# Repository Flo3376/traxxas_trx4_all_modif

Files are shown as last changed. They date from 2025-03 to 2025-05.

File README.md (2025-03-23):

# 🚗 Projet TRX4 Sport Hummer – Upgrade et Documentation complète

> 🇬🇧 [Switch to English version](./README.en.md)

Bienvenue sur ce projet de modification complète du **Traxxas TRX4 Sport 1/10**, basé à l'origine sur des éléments publiés sur Thingiverse, mais entièrement remis au propre, restructuré et enrichi.  
L’objectif est de proposer un **montage propre, solide, et documenté section par section**, avec une **carrosserie type Hummer** se montant en lieu et place, sans aucune modification des pièces d’origine.

---

## 🎯 Objectifs

- Offrir une **carrosserie réaliste** qui se monte comme si elle venait directement de chez Traxxas
- Ajouter une **gestion d’éclairage maison**, quelques options pratiques pour l’utilisation et le stockage
- Garder **la compatibilité maximale** avec les options d’origine (2 vitesses, différentiels débrayables…)
- Rester simple à monter, **sans découpe ni bidouillage** destructif (idéal pour ne pas casser la garantie)

---

## 🔧 Moyens et outils

Ce projet est réalisé entièrement **par un passionné** : modélisation, câblage, code et documentation.

- 🧩 **Conception 3D** : [Fusion 360](https://www.autodesk.com/products/fusion-360)
- 🔌 **Électronique** : schémas réalisés avec [Fritzing](https://fritzing.org/)
- 💡 **Firmware** : développé avec [Arduino IDE](https://www.arduino.cc/en/software)
- 🖨️ **Fabrication** :
  - Imprimante 3D avec buse de 0.8mm (robustesse)
  - Impression en **PETG**
  - Fer à souder de base, composants électroniques accessibles

Chaque section (carrosserie, électronique, firmware…) contient ses propres fichiers, schémas, images et instructions détaillées.

---

## 📂 Sommaire des sections

| Section | Description |
|---|---|
| [🛠️ Carrosserie](./carrosserie/README.md) | Montage de la coque Hummer, supports imprimés, ajustement sans modif. |
| [⚡ Électronique](./electronique/README.md) | Soudure, schéma de câblage, composants utilisés. |
| [💾 Firmware](./firmware/README.md) | Flash du microcontrôleur, gestion de l’éclairage, code Arduino. |

---

## 🧠 Pour qui ?

Ce projet est **ouvert à tous** : découpé en modules indépendants pour que chacun puisse piocher ce qui l’intéresse.  
Il est pensé pour être accessible à **des débutants débrouillards** comme à des passionnés expérimentés.  
L’ambition est de **tout expliquer simplement**, même si la doc évoluera au fil du temps.

🙏 Merci d’être indulgent : certaines approches sont simples, parfois pas optimales, mais pensées pour être faisables sans matériel pro.

---

## 🚀 Évolution & perspectives

- ✅ Une **télémétrie de base** est déjà intégrée
- 🛰️ Une **boîte noire GPS** est envisagée à terme
- 🧪 Ce projet est vivant : vos retours et suggestions sont les bienvenus

---

## 💬 Rejoindre la communauté

Pour discuter du projet, poser vos questions, ou partager vos montages :  
➡️ **[Rejoignez le serveur Discord](https://discord.gg/4V3BPrqjAZ)**

---

## ☕ Me soutenir ?

Ce projet m’a demandé **pas mal de temps, de prototypage, de documentation et de tests**.  
Je ne cherche pas à me payer une villa au Bahamas 😅 — mais si ce travail vous aide et que vous voulez me remercier...

🎁 **Un petit don pour m’aider à m’acheter 2 bobines de PETG, une boîte de visserie ou quelques inserts ferait super plaisir !**  
👉 [Faire un don via PayPal](https://www.paypal.com/donate/?hosted_button_id=264K3SDVHKDK2)

---

👉 **Explorez les différentes sections via le sommaire ci-dessus pour commencer l'aventure !**

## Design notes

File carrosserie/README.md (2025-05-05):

# 🛠️ Carrosserie – Montage et Fixation

## PRÉAMBULE

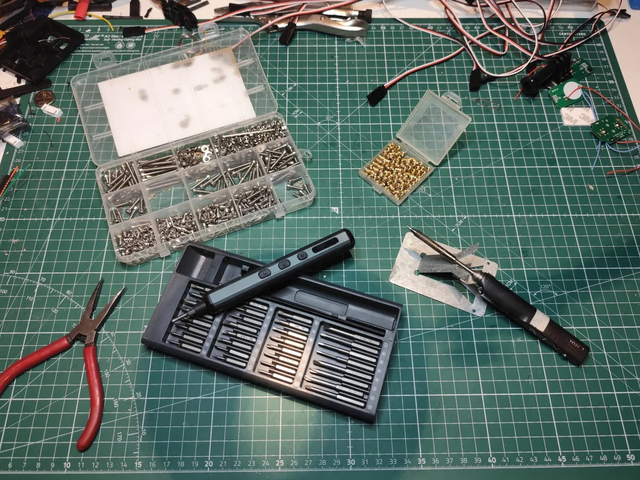
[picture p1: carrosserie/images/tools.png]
Outils


Faut être clair : ce projet va te prendre 100 heures facile. Impression, ponçage, ajustements, montage... Et tout ce temps, ton 4x4 restera à poil sur des cales, aussi mobile qu’un meuble IKEA pas monté.

C’est pas une bricole du dimanche, c’est un chantier. Si t’es pas prêt à y passer tes soirées, tes week-ends et à ruiner une chemise avec de la cyano, c’est maintenant qu’il faut faire demi-tour.

Matos minimum :
- Un kit de visserie 3 mm métrique (perso j’ai pris un mille-pièces, c’est pas pour frimer, c’est pour survivre).

- Des inserts filetés 3 mm, les vrais, ceux qui tiennent.

- D’un fer à souder de précision, pas ton vieux machin à griller les ESC.

- Et un joyeux bordel sur ton établi. Parce qu’un espace trop propre, c’est pas crédible. Et franchement, t’as déjà vu un maker qui bosse dans un bloc opératoire ?

- Du café. Beaucoup. En poudre, en grain, en perfusion si nécessaire. Sans ça, t’iras pas au bout. Si t’en arrives à infuser des copeaux de PLA pour rester éveillé, t’as été trop loin.

Et quand tu peindras ta caisse... libre à toi d’y mettre la couleur que tu veux. Tant que c’est couleur sable, bien sûr.

---

## Étape 1 – Les chandelles

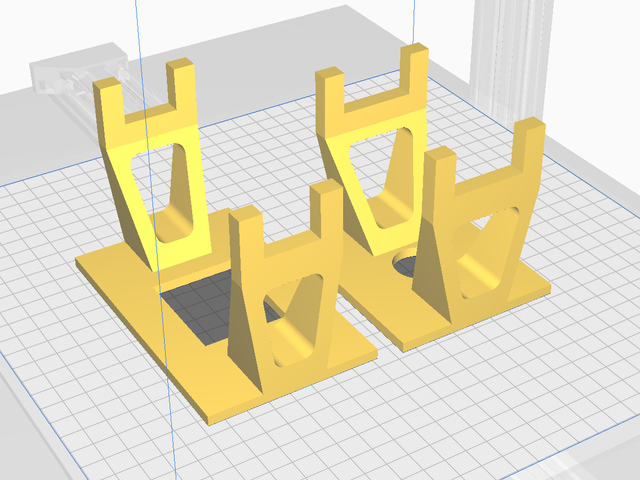
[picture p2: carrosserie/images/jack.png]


[📦 STL des chandelles avant](https://github.com/Flo3376/traxxas_trx4_all_modif/raw/main/carrosserie/parts/jack_stands/jack_stands_F.stl)
[📦 STL des chandelles arrière](https://github.com/Flo3376/traxxas_trx4_all_modif/raw/main/carrosserie/parts/jack_stands/jack_stands_R.stl)

On va commencer par imprimer les chandelles:
- 0.8mm pour la buse
- Orientation : socle vers le bas, évidemment. Pas la peine de faire les malins avec des supports tordus dès le départ. Ça dérapera bien assez tout seul plus tard.
- Adhérence par jupe conseillée
- support oui

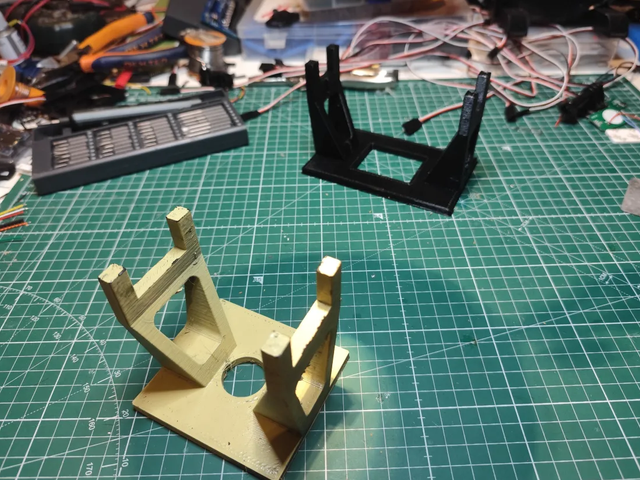
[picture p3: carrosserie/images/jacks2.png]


La chandelle avec le rond dans le socle c'est pour le train avain, celle avec le trou carré, tu devines pour quoi c’est....
Si tu bloques déjà ici... comment dire... Ça promet pour la suite. Vraiment.

## Étape 2 – Dépose des éléments en trop
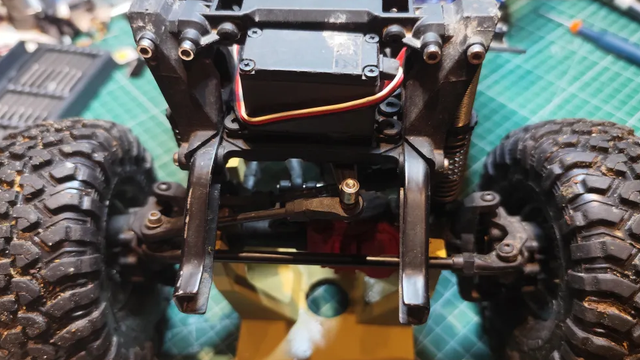
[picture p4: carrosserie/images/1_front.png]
Avant

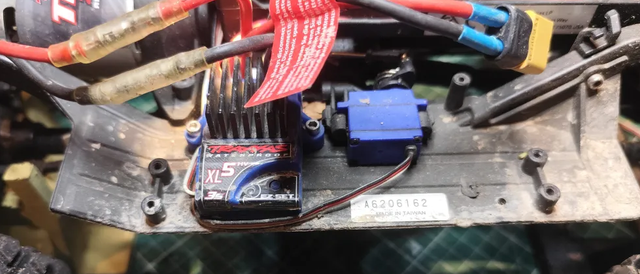
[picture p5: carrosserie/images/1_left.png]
Gauche

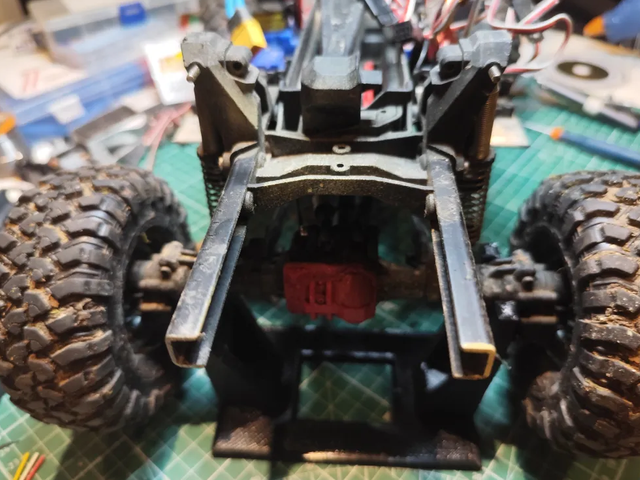
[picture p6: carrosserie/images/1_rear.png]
Arrière

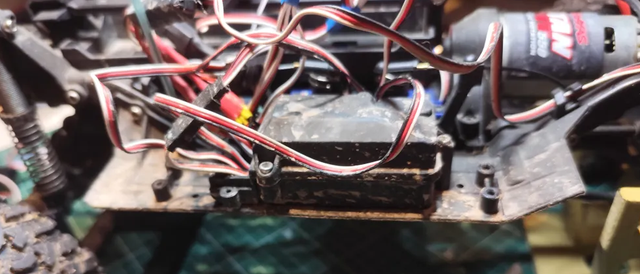
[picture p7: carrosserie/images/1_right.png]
Droites


Pas de quartier :

- Supports de carrosserie

- Supports de pare-choc

- Marchepieds

Tout ça, dehors. On vire tout ce qui dépasse. Ce qui reste doit être prêt à accueillir du neuf, du solide, du printé maison.

Les photos montrent une version équipée de la boîte 2 rapports et des commandes de blocage de ponts. Si t’as pas ça, pas grave. Mais sache que t’es déjà jaloux, un peu.

🛠️ Note sérieuse :
À ce stade, y’a aussi le support batterie qui pourrait bien y passer.
Je dis rien pour l’instant, mais j’ai une idée qui va peut-être émerger. Ou exploser. On verra. Mais ça sera une option 

💥 Concernant le câblage :
Ne paniquez pas si c’est un sac de nœuds. Si vous voyiez le câblage dans ma tête, vous relativiseriez tout de suite. Comme on dit chez nous :

> "Tous les étages sont câblés, mais pour le voltage, on repassera."

🔍 Remarque :
Il manque une pièce sur le train arrière, celle qui relie les suspensions. Elle n’est pas forcément à démonter, c’est juste que je l’ai perdue lors d’un road trip sans carrosserie. Si vous, vous l’avez encore, tant mieux. Sinon, bienvenue au club.

Et pendant qu’on y est : un petit nettoyage, ça mange pas de pain. C’est quand même plus agréable de bosser sur un engin propre.
(Et non, pas de blague douteuse sur "votre engin", merci. On a dit propre.)

## Étape 2 – La charnière de capot avant

[📦 STL de la charnière avant](https://github.com/Flo3376/traxxas_trx4_all_modif/raw/main/carrosserie/parts/hinge_hood_front_v3/hinge_hood_front_v3.stl)

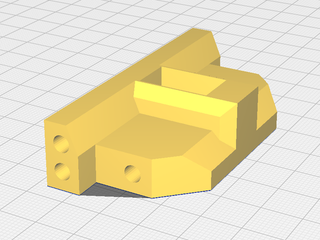
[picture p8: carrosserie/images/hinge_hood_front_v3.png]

- 0.8mm pour la buse
- À imprimer comme sur l’image.
Pourquoi ? Pour éviter que la pièce se fasse cisailler au premier face-à-face non consenti avec un obstacle. Ça semble con, mais tu seras content que ça tienne.
- support non

---

⚙️ Première pièce à installer.
Il vous fraudra :
- 6 inserts
- 4 vis en M3x10mm

---

⚠️ Précautions à prendre pour pas faire n’importe quoi dès le début :
- Afin de rentrer les inserts proprement et sans forcer comme un goret, il faut les chauffer quelques instants à température élevée.
Mon fer, lui, démarre à 300°C par défaut. C’est pas pour faire style, c’est parce que ça marche.

Et voici un dicton d’un grand sage – gravé par la douleure. À mémoriser absolument :
> Ta main tremblera, ton insert tombera.
 Le rattraper tu voudras.
 Ce réflexe à la con, tu auras.

- Serrage à la main, pas comme un bourrin avec une visseuse.
- Pas de rondelles : de toute façon ça passe pas.
- Pas de frein filet, inutile ici.
- Et la face plane vers l’avant, pas besoin de vous faire un dessin (enfin si, y’a les photos).

>la dépose des roues avant n'est pas obligatoire, mais ça peut être pratique

---
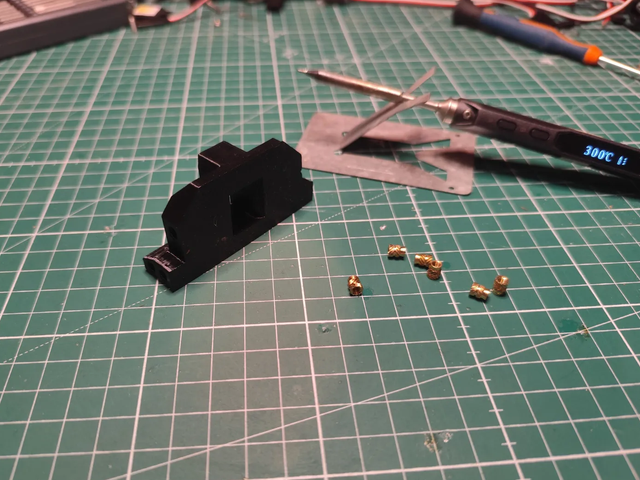
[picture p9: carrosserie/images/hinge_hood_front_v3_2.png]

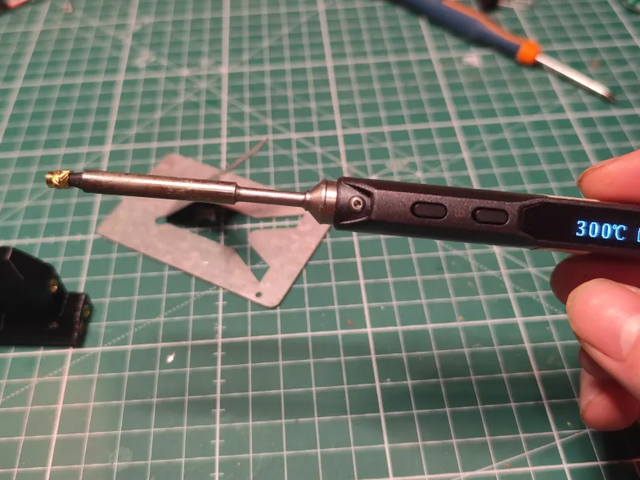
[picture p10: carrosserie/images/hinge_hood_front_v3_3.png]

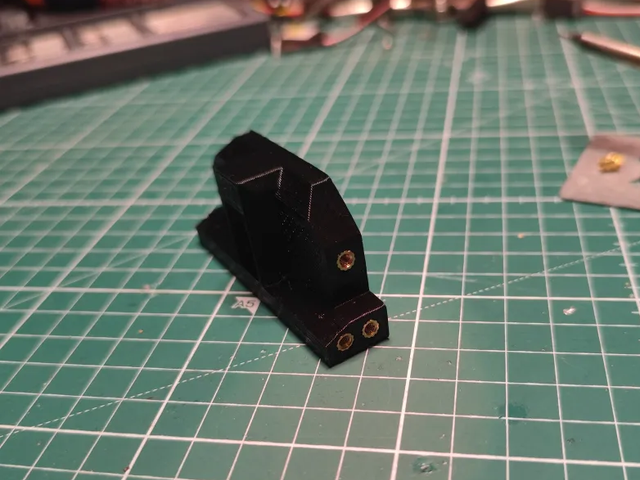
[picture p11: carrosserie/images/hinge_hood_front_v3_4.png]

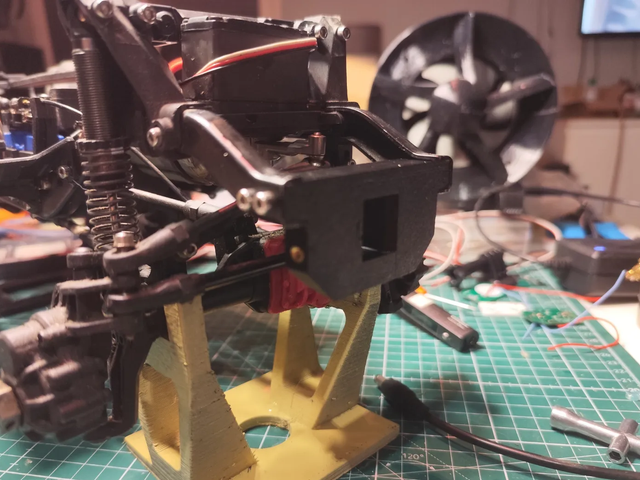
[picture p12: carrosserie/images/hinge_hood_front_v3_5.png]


## Étape 3, 4, 5 et, ...et... et pis merde– Le capot, son support, la façade,...

[📦 STL du support capot](https://github.com/Flo3376/traxxas_trx4_all_modif/raw/main/carrosserie/parts/hood_mount_frame_v3/hood_mount_frame_v3.stl)
[📦 STL de face avant](https://github.com/Flo3376/traxxas_trx4_all_modif/raw/main/carrosserie/parts/body_front_face_v2/body_front_face_v2.stl)
[📦 STL du capot](https://github.com/Flo3376/traxxas_trx4_all_modif/raw/main/carrosserie/parts/hood/hood.stl)
[📦 STL support des angels eyes](https://github.com/Flo3376/traxxas_trx4_all_modif/raw/main/carrosserie/parts/angel/angel_v1.stl)

---
support de capot

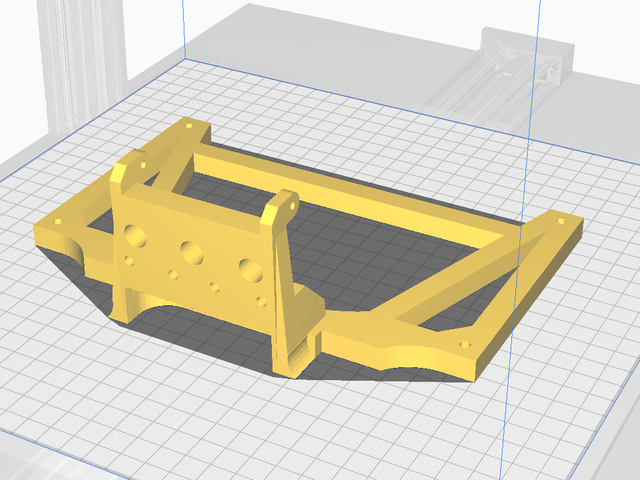
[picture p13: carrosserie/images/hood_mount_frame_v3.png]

- 0.8mm pour la buse
- Sens d'impression selon votre choix de défaut.
  - Comme sur l’image : ça va wrapper, mais comme c’est caché, ça restera notre petit secret.
  - Debout (façade contre plateau) : vous allez cramer du filament pour des supports, et si votre machine a la tremblote à en sucrer les fraises, c’est foutu.
  - Sur le côté : mélange des deux emmerdes. À vous de voir.
  - support non

---
façade avant

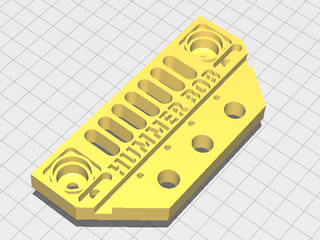
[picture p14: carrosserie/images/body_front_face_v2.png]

- 0.8mm pour la buse
- À imprimer comme sur l’image, si vous n'avez pas de soucis d'adhérence au plateau.
- support oui

---
angel eyes (optionnel)

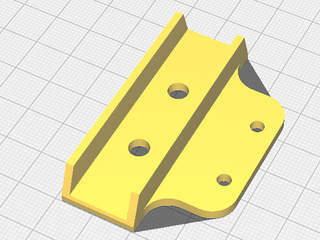
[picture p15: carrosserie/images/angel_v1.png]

- 0.8mm pour la buse
- À imprimer comme sur l’image.
- support non

---
capot

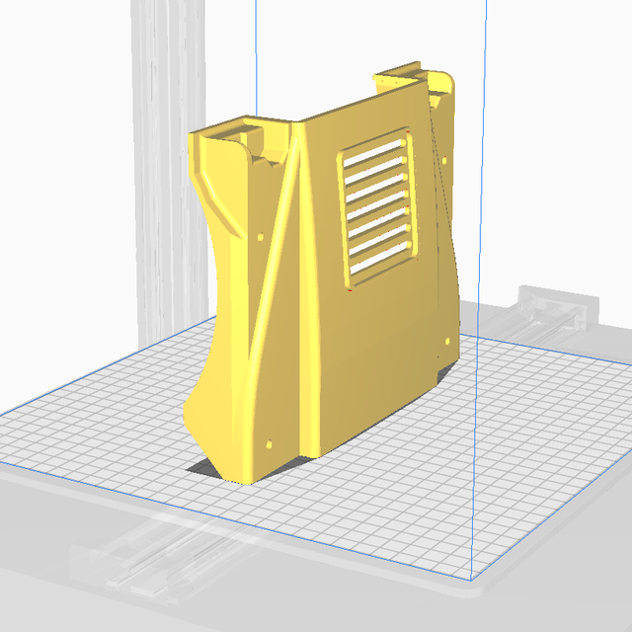
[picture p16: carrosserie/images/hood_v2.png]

- 0.8mm pour la buse
- À imprimer comme sur l’image pour éviter que les couches se voit trop
- imprimante au ralentie, ça limitera les dégats de colision.
- Adhérence par jupe obligatoire / radeau conseillé pour les machines un peu plus capricieuse
- support oui

---
Bon la ça va commencer à donner le sourrire.
Une fois que vous avez nettoyer les pièces, il va vous falloir:
- 8 insert (ça commence à faire mais vous avez 10 doigts, vous vous en sortirer)
- 4 ou 2 vis M3 x 10mm pour fixer la façade (je ne vous ai pas dit de la monter bordel.) Si vous ne montez pas l'option Angel eye c'est 4, sinon remplacer les 2 vis du centre par des M3x20mm.
- 2 vis M3 x 15mm  et 2 M3 x 18mm+ rondelle pour fixer le capot (range cette putain de visseuse, je ne le dirai pas 2 fois)
- 2 vis M3 x 12mm + si vous avez une lichette de frein filet léger

🛠️ Étapes de montage
- Pose des 8 inserts sur le support capot :
  - 4 sur la façade
  - 1 sur chaque coin du support
  >4 + 4 = 8, on valide.

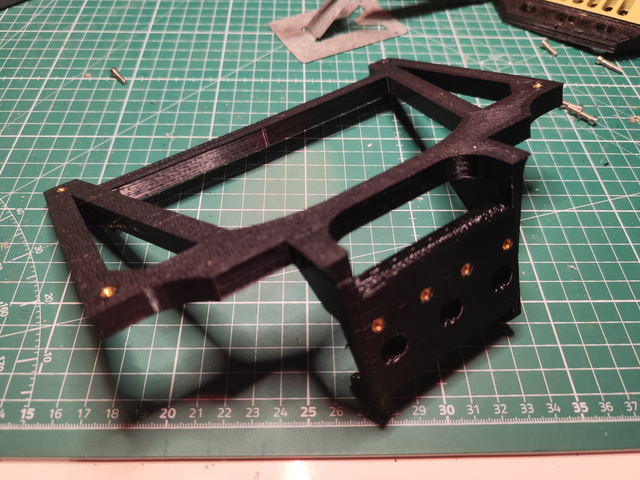
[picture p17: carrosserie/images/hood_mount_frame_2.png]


---

- Fixation de la façade :
  - Si vous utilisez les Angel Eyes :
    - Vissez les 2 vis externes
    - Glissez le support LED avec les deux LEDs déjà montées par le haut
      (si tu fais pas ça dans l’ordre, viens pas pleurer)
    - Puis serrez les 2 vis centrales
  - Sinon, 4 vis M3 x 10mm direct.

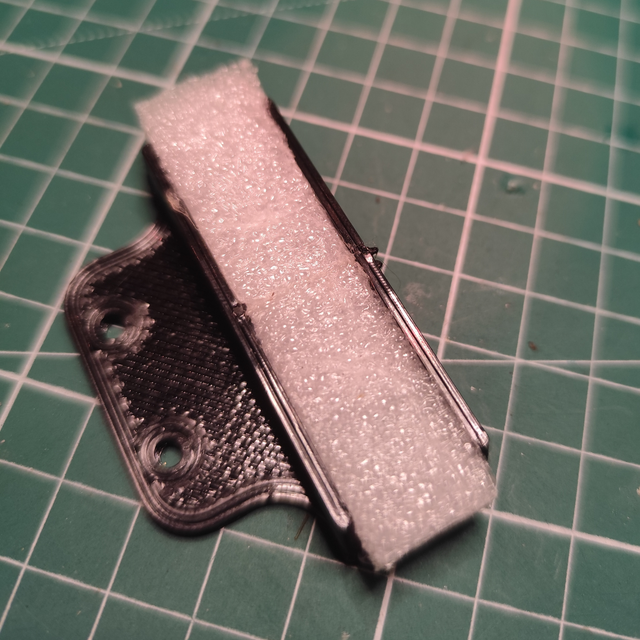
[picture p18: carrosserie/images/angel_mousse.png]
angel eye

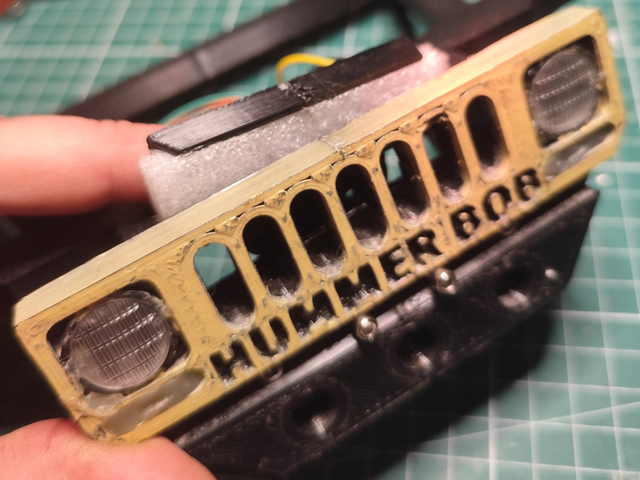
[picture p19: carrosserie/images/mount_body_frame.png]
façade

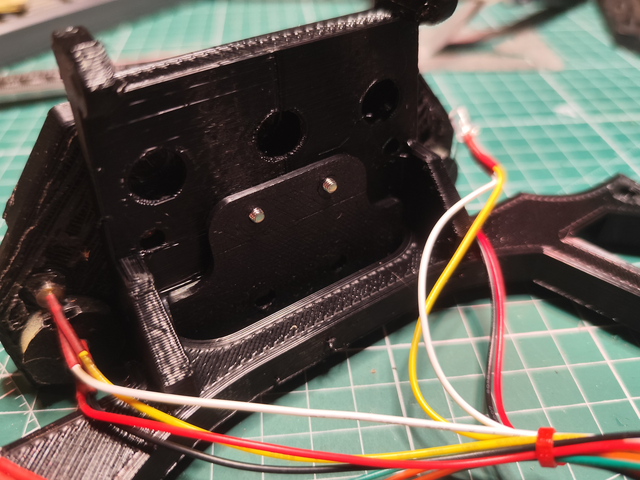
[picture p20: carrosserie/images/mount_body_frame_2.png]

---

- Fixation du support capot sur la charnière :
  - Utilisez les 2 vis M3 x 12 mm
  - Pour le premier montage ne mettez de frein filet
    > vous devrez certaine le déposer pour faciliter la suite du montage) ,
  - Pour le montage définitif, mettez une micro goutte de frein filet 
    > (Pas un bain. Une goutte. Sérieux.)
  - Serrez, puis desserrez d’un tour.
    > Vous ne le faites pas ? Vous allez la voir passer, la douille, surtout avec le frein filet.

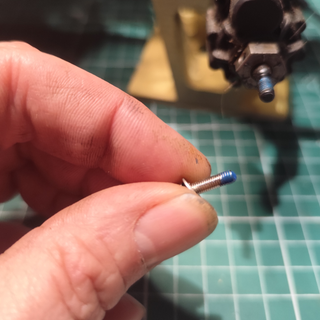
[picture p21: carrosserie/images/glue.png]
glue


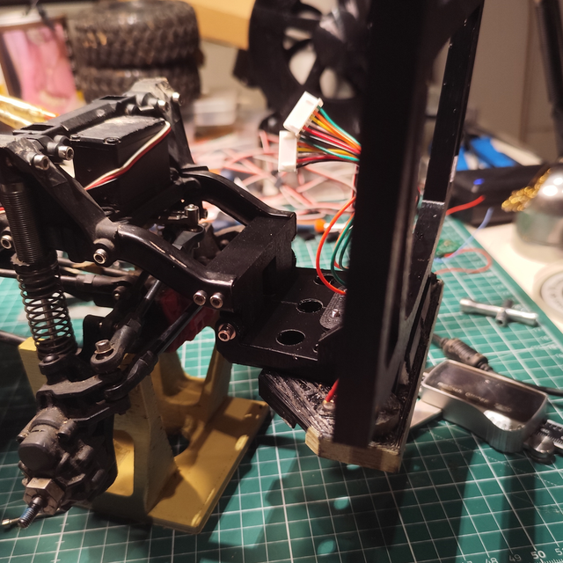
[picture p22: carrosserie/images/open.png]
open

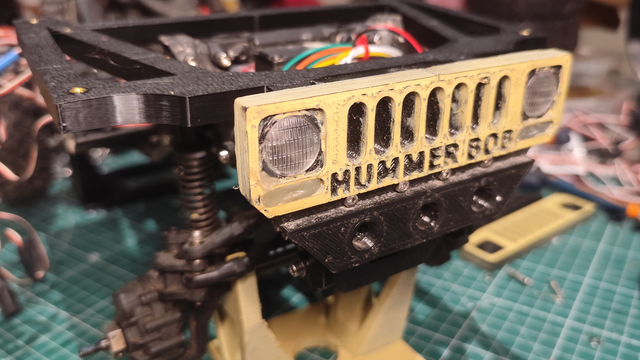
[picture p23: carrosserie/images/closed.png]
closed


---

- Pose du capot :
  - Allez-y, posez le capot, mais ne serrez rien pour l’instant.
  - Mettez les 2 vis de 18 mm sur les zones les plus épaisses, les 2 plus courtes (15 mm) à l’avant, côté museau.
  - Il y aura des ajustements, donc on garde de la marge.
  - Astuce : ne pas serrer tout de suite facilite l’engagement dans les inserts sans les ruiner. Et ça évite de tout recommencer.

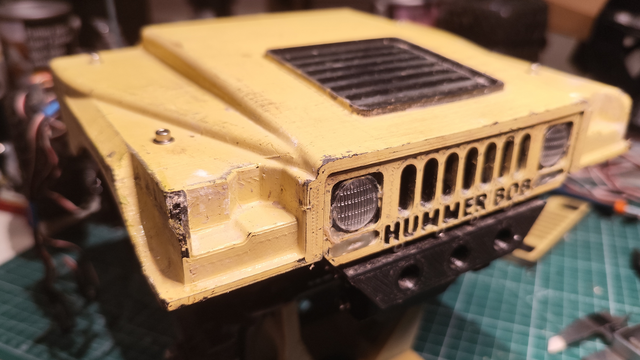
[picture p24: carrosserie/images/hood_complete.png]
hood_complete


Et voilà. On marque une pause, on recule de deux pas, et on admire.
Prenez 5 minutes pour souffler... et pour siroter un café.
Vous l’avez mérité.

## Étape 7 (enfin je crois), Préparation du rigidifieur arrière et des supports:

[📦 STL du rigidifieurt](https://github.com/Flo3376/traxxas_trx4_all_modif/raw/main/carrosserie/parts/rear_chassis_brace/rear_chassis_brace.stl)

rigidifieur arrière
- 0.8mm pour la buse
- À imprimer comme sur l’image, aucun piéges.

🧱 Le rigidifieur (aka la traverse qui tient la baraque)
Avant tout, faut préparer le rigidifieur, cette pièce qu’on vient se caler entre les deux longerons du châssis.

Il faut y poser 7 inserts. Pas 6. Pas 8. Sept.

Et prévoir 6 vis M3 x 10 mm avec rondelles pour la suite.

Si t’en rates un, tu vas t’en souvenir au moment de l’assemblage. Et ce sera trop tard. Donc on le fait bien maintenant, pendant que t’as encore les doigts intacts.

rigidifieur arrière

---
🔧 Le support droit/gauche (arrière)
[📦 STL du support droit et gauche](https://github.com/Flo3376/traxxas_trx4_all_modif/raw/main/carrosserie/parts/rear_mount_v2/rear_mount_right_v2.stl)

>Le support gauche → n’existe pas en STL, parce qu’on n’est pas là pour faire du copier-coller à la main.
>Il suffit de dupliquer le support droit dans Cura et d’activer la symétrie miroir sur l’axe X.

support arrière
- 0.8mm pour la buse
- À debout et pensez à dupliquer la piéces avec un symétrie en X.
- Supports conseillé

Les supports sont des pièces relativement massive qui vont supporter la carroserie et encaisser une partie des chocs
Pour chaque support il va falloir 3 ou 5 inserts (5 si vous pensez accrochez quelque chose au rigidifieur comme un atttelage, oups j'ai en trop dit sur une prochaine idée).
La pose des insert utilise une approche différente car dedans nous laisseront des vis permanantes.
La pose des inserts se fait par le dessous. et une fois poser, il faudra mettre des vis M3 x 18mm avec des rondelles aussi par le dessous.

La fixation/laison entre le rigidifieur et les supports se fait grace à des vis M3 x 12mm avec aussi des rondelles.

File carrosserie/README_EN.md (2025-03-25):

# 🛠️ Carrosserie – Montage et Fixation

## FOREWORD

Tools

Before diving into the wonderful world of custom-printed car bodies, let’s be clear: between printing time, painting (you're on your own here, Picasso), assembly, and all the fiddly adjustments that would make a Swiss watchmaker cry, expect to spend around 100 hours. Yep. One hundred. During that time, your beautiful 4x4 will be completely out of service—naked and sad, with nothing on its chassis.

You’ll need:
- A 3 mm metric screw kit (I got a 1000-piece one, because why not go overkill?).

- Threaded inserts for 3 mm screws.

- A small soldering iron to install those inserts properly (not your wire-soldering one, a real precision iron).

- And above all: a lot of clutter around your workspace. If it’s too clean, it doesn’t feel like a real maker zone. Chaos is fuel.

---

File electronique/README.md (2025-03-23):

# ⚡ Électronique – Schéma et Soudure

## Composants

- ESC
- Moteur brushless
- Batterie LiPo
- Récepteur

## Schéma de câblage

Schéma de câblage

| 🇬🇧 English | 🇫🇷 Français |
|---|---|
| Double-check all connections before powering up. | Vérifiez toutes les connexions avant d’alimenter le circuit. |

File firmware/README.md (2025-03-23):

# 💾 Firmware – Configuration et Code

## Préparation

- Installez PlatformIO ou Arduino IDE
- Branchez le microcontrôleur via USB

## Flash

```bash
pio run --target upload
```

## Code source

Le dossier `code/` contient les fichiers du firmware.

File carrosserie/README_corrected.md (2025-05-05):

# 🛠️ Carrosserie – Montage et Fixation

## PRÉAMBULE

Outils

Faut être clair : ce projet va te prendre 100 heures facile. Impression, ponçage, ajustements, montage... Et tout ce temps, ton 4x4 restera à poil sur des cales, aussi mobile qu’un meuble IKEA pas monté.

C’est pas une bricole du dimanche, c’est un chantier. Si t’es pas prêt à y passer tes soirées, tes week-ends et à ruiner une chemise avec de la cyano, c’est maintenant qu’il faut faire demi-tour.

Matos minimum :
- Un kit de visserie 3 mm métrique (perso j’ai pris un mille-pièces, c’est pas pour frimer, c’est pour survivre).

- Des inserts filetés 3 mm, les vrais, ceux qui tiennent.

- D’un fer à souder de précision, pas ton vieux machin à griller les ESC.

- Et un joyeux bordel sur ton établi. Parce qu’un espace trop propre, c’est pas crédible. Et franchement, t’as déjà vu un maker qui bosse dans un bloc opératoire ?

- Du café. Beaucoup. En poudre, en grain, en perfusion si nécessaire. Sans ça, t’iras pas au bout. Si t’en arrives à infuser des copeaux de PLA pour rester éveillé, t’as été trop loin.

Et quand tu peindras ta caisse... libre à toi d’y mettre la couleur que tu veux. Tant que c’est couleur sable, bien sûr.

---

## Étape 1 – Les chandelles

Chandelles

[📦 STL des chandelles avant](https://github.com/Flo3376/traxxas_trx4_all_modif/raw/main/carrosserie/parts/jack_stands/jack_stands_F.stl)
[📦 STL des chandelles arrière](https://github.com/Flo3376/traxxas_trx4_all_modif/raw/main/carrosserie/parts/jack_stands/jack_stands_R.stl)

On va commencer par imprimer les chandelles:
- 0.8mm pour la buse
- Orientation : socle vers le bas, évidemment. Pas la peine de faire les malins avec des supports tordus dès le départ. Ça dérapera bien assez tout seul plus tard.
- Adhérence par jupe conseillée
- - Support : **oui**

Chandelles

La chandelle avec le rond dans le socle c'est pour le train avant, celle avec le trou carré, tu devines pour quoi c’est....
Si tu bloques déjà ici... comment dire... Ça promet pour la suite. Vraiment.

## Étape 2 – Dépose des éléments en trop
Avant
Gauche
Arrière
Droites

Pas de quartier :

- Supports de carrosserie
- Supports de pare-choc
- Marchepieds

Tout ça, dehors. On vire tout ce qui dépasse. Ce qui reste doit être prêt à accueillir du neuf, du solide, du printé maison.

Les photos montrent une version équipée de la boîte 2 rapports et des commandes de blocage de ponts. Si t’as pas ça, pas grave. Mais sache que t’es déjà jaloux, un peu.

🛠️ Note sérieuse :
À ce stade, y’a aussi le support batterie qui pourrait bien y passer.
Je dis rien pour l’instant, mais j’ai une idée qui va peut-être émerger. Ou exploser. On verra. Mais ça sera une option 

💥 Concernant le câblage :
Ne paniquez pas si c’est un sac de nœuds. Si vous voyiez le câblage dans ma tête, vous relativiseriez tout de suite. Comme on dit chez nous :

> "Tous les étages sont câblés, mais pour le voltage, on repassera."

🔍 Remarque :
Il manque une pièce sur le train arrière, celle qui relie les suspensions. Elle n’est pas forcément à démonter, c’est juste que je l’ai perdue lors d’un road trip sans carrosserie. Si vous, vous l’avez encore, tant mieux. Sinon, bienvenue au club.

Et pendant qu’on y est : un petit nettoyage, ça mange pas de pain. C’est quand même plus agréable de bosser sur un engin propre.
(Et non, pas de blague douteuse sur "votre engin", merci. On a dit propre.)

## Étape 2 – La charnière de capot avant

[📦 STL de la charnière avant](https://github.com/Flo3376/traxxas_trx4_all_modif/raw/main/carrosserie/parts/hinge_hood_front_v3/hinge_hood_front_v3.stl)

charnière
- 0.8mm pour la buse
- À imprimer comme sur l’image.
Pourquoi ? Pour éviter que la pièce se fasse cisailler au premier face-à-face non consenti avec un obstacle. Ça semble con, mais tu seras content que ça tienne.
- Support : **non**

---

⚙️ Première pièce à installer.
Il vous faudra :
- 6 inserts
- 4 vis en M3x10mm

---

⚠️ Précautions à prendre pour pas faire n’importe quoi dès le début :
- Afin de rentrer les inserts proprement et sans forcer comme un goret, il faut les chauffer quelques instants à température élevée.
Mon fer, lui, démarre à 300°C par défaut. C’est pas pour faire style, c’est parce que ça marche.

Et voici un dicton d’un grand sage – gravé par la douleure. À mémoriser absolument :
> Ta main tremblera, ton insert tombera.
 Le rattraper tu voudras.
 Ce réflexe à la con, tu auras.

- Serrage à la main, pas comme un bourrin avec une visseuse.
- Pas de rondelles : de toute façon ça passe pas.
- Pas de frein filet, inutile ici.
- Et la face plane vers l’avant, pas besoin de vous faire un dessin (enfin si, y’a les photos).

>la dépose des roues avant n'est pas obligatoire, mais ça peut être pratique

---
charnière
charnière
charnière
charnière

## Étape 3, 4, 5 et, ...et... et pis merde– Le capot, son support, la façade,...

[📦 STL du support capot](https://github.com/Flo3376/traxxas_trx4_all_modif/raw/main/carrosserie/parts/hood_mount_frame_v3/hood_mount_frame_v3.stl)
[📦 STL de face avant](https://github.com/Flo3376/traxxas_trx4_all_modif/raw/main/carrosserie/parts/body_front_face_v2/body_front_face_v2.stl)
[📦 STL du capot](https://github.com/Flo3376/traxxas_trx4_all_modif/raw/main/carrosserie/parts/hood/hood.stl)
[📦 STL support des angels eyes](https://github.com/Flo3376/traxxas_trx4_all_modif/raw/main/carrosserie/parts/angel/angel_v1.stl)

---
support de capot

support
- 0.8mm pour la buse
- Sens d'impression selon votre choix de défaut.
  - Comme sur l’image : ça va wrapper, mais comme c’est caché, ça restera notre petit secret.
  - Debout (façade contre plateau) : vous allez cramer du filament pour des supports, et si votre machine a la tremblote à en sucrer les fraises, c’est foutu.
  - Sur le côté : mélange des deux emmerdes. À vous de voir.
  - Support : **non**

---
façade avant

support
- 0.8mm pour la buse
- À imprimer comme sur l’image, si vous n'avez pas de soucis d'adhérence au plateau.
- Support : **oui**

---
angel eyes (optionnel)

support
- 0.8mm pour la buse
- À imprimer comme sur l’image.
- Support : **non**

---
capot

support
- 0.8mm pour la buse
- À imprimer comme sur l’image pour éviter que les couches se voit trop
- imprimante au ralentie, ça limitera les dégats de collision.
- Adhérence : jupe obligatoire, radeau conseillé pour les machines un peu plus capricieuse
- Support : **oui**

---
Bon la ça va commencer à donner le sourrire.
Une fois que vous avez nettoyer les pièces, il va vous falloir:
- 8 insert (ça commence à faire mais vous avez 10 doigts, vous vous en sortirez)
- 4 ou 2 vis M3 x 10mm pour fixer la façade (je ne vous ai pas dit de la monter bordel.) Si vous ne montez pas l'option Angel eye c'est 4, sinon remplacez les 2 vis du centre par des M3x20mm.
- 2 vis M3 x 15mm  et 2 M3 x 18mm+ rondelle pour fixer le capot (range cette putain de visseuse, je ne le dirai pas 2 fois)
- 2 vis M3 x 12mm + si vous avez une micro-goutte de frein filet léger

🛠️ Étapes de montage
- Pose des 8 inserts sur le support capot :
  - 4 sur la façade
  - 1 sur chaque coin du support
  >4 + 4 = 8, on valide.

support

---

- Fixation de la façade :
  - Si vous utilisez les Angel Eyes :
    - Vissez les 2 vis externes
    - Glissez le support LED avec les deux LEDs déjà montées par le haut
      (si tu fais pas ça dans l’ordre, viens pas pleurer)
    - Puis serrez les 2 vis centrales
  - Sinon, 4 vis M3 x 10mm direct.

angel eye
façade
angel eye
---

- Fixation du support capot sur la charnière :
  - Utilisez les 2 vis M3 x 12 mm
  - Pour le premier montage ne mettez de frein filet
    > vous devrez certaine le déposer pour faciliter la suite du montage) ,
  - Pour le montage définitif, mettez une micro goutte de frein filet 
    > (Pas un bain. Une goutte. Sérieux.)
  - Serrez, puis desserrez d’un tour.
    > Vous ne le faites pas ? Vous allez la voir passer, la douille, surtout avec le frein filet.

glue

open
closed

---

- Pose du capot :
  - Allez-y, posez le capot, mais ne serrez rien pour l’instant.
  - Mettez les 2 vis de 18 mm sur les zones les plus épaisses, les 2 plus courtes (15 mm) à l’avant, côté museau.
  - Il y aura des ajustements, donc on garde de la marge.
  - Astuce : ne pas serrer tout de suite facilite l’engagement dans les inserts sans les ruiner. Et ça évite de tout recommencer.

hood_complete

Et voilà. On marque une pause, on recule de deux pas, et on admire.
Prenez 5 minutes pour souffler... et pour siroter un café.
Vous l’avez mérité.

## Étapes 7, 8 et 9 (enfin je crois), Préparation du rigidifieur arrière et des supports:

[📦 STL du rigidifieur](https://github.com/Flo3376/traxxas_trx4_all_modif/raw/main/carrosserie/parts/rear_chassis_brace/rear_chassis_brace.stl)

rigidifieur arrière
- 0.8mm pour la buse
- À imprimer comme sur l’image, aucun pièges.

🧱 Le rigidifieur (aka la traverse qui tient la baraque)
Avant tout, faut préparer le rigidifieur, cette pièce qu’on vient se caler entre les deux longerons du châssis.

Il faut y poser 7 inserts. Pas 6. Pas 8. Sept.

Et prévoir 6 vis M3 x 10 mm avec rondelles pour la suite.

Si t’en rates un, tu vas t’en souvenir au moment de l’assemblage. Et ce sera trop tard. Donc on le fait bien maintenant, pendant que t’as encore les doigts intacts.

rigidifieur arrière

---
🔧 Le support droit/gauche (arrière)
[📦 STL du support droit (et gauche par symétrie)](https://github.com/Flo3376/traxxas_trx4_all_modif/raw/main/carrosserie/parts/rear_mount_v2/rear_mount_right_v2.stl)

>Le support gauche → n’existe pas en STL, parce qu’on n’est pas là pour faire du copier-coller à la main.
>Il suffit de dupliquer le support droit dans Cura et d’activer la symétrie miroir sur l’axe X.

support arrière
- 0.8mm pour la buse
- À debout et pensez à dupliquer la pièces avec un symétrie en X.
- Supports conseillés

Les supports sont des pièces relativement massives, qui vont supporter la carrosserie et encaisser une partie des chocs.

Pour chaque support, il va falloir :
- 3 inserts en usage classique
- 5 inserts si vous comptez fixer quelque chose au rigidifieur (genre un attelage, oups... j’en ai trop dit sur une idée future)

La pose des inserts ici est un peu différente : on laisse les vis dedans, volontairement.
Les inserts se posent par le dessous, et une fois en place, on met des vis M3 x 18 mm avec rondelles, également par dessous.

support arrière
support arrière2
support arrière3
support arrière4

La fixation/laison entre le rigidifieur et les supports se fait grace à des vis M3 x 12mm avec aussi des rondelles.

support arrière5
support arrière6

Et voilà.
À force de parler de rondelles, j’ai envie de saucisson.

Allez, apéro. 🍷🧀

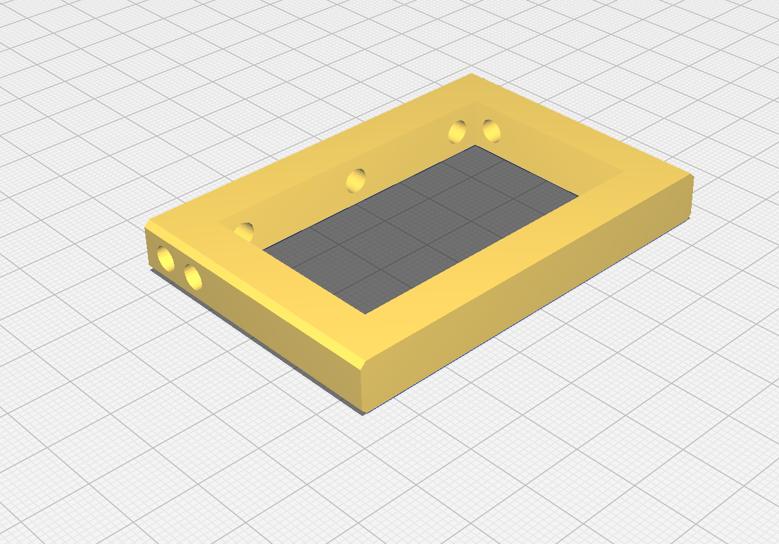
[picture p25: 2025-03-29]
carrosserie/parts/rear_chassis_brace/rear_chassis_brace.png

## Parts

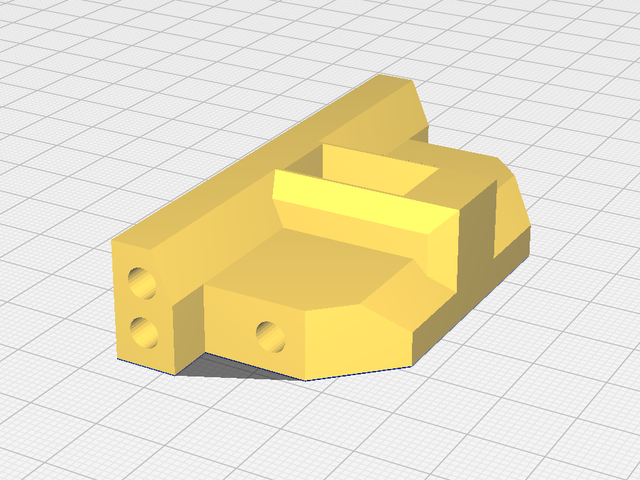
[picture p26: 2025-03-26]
carrosserie/parts/hinge_hood_front_v3/hinge_hood_front_v3.png

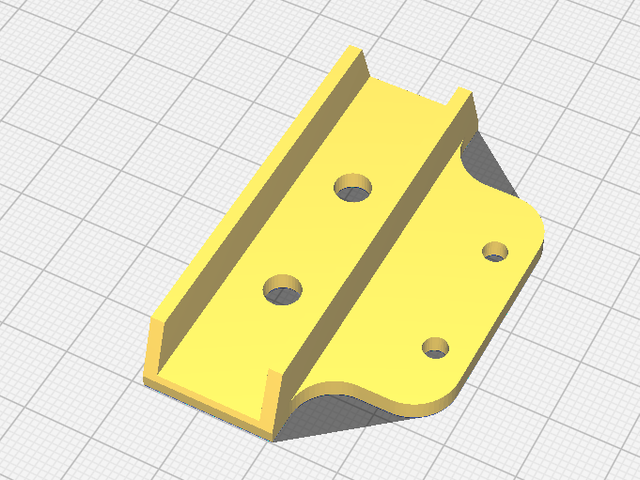
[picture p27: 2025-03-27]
carrosserie/parts/angel/angel v1.png

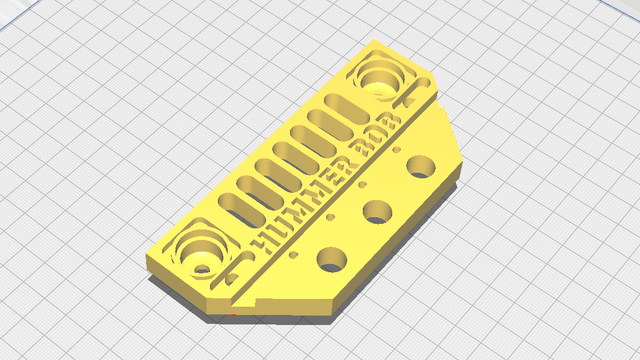
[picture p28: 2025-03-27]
carrosserie/parts/body_front_face_v2/body_front_face_v2.png

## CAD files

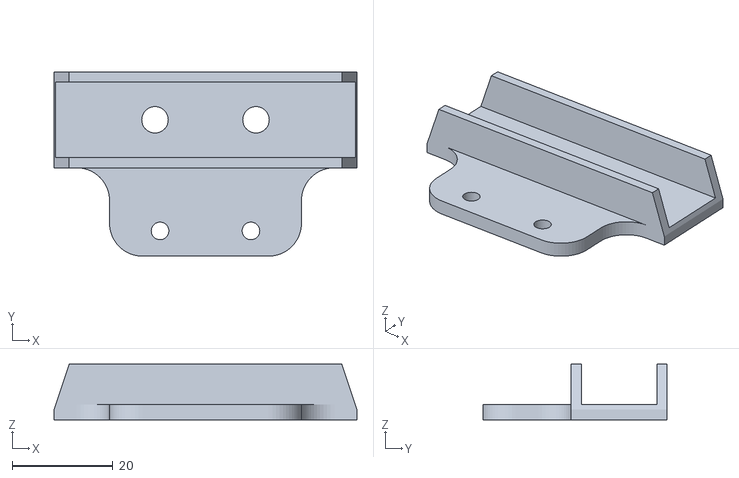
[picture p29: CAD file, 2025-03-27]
carrosserie/parts/angel/angel v1.stl
60.0 x 36.5 x 11.0

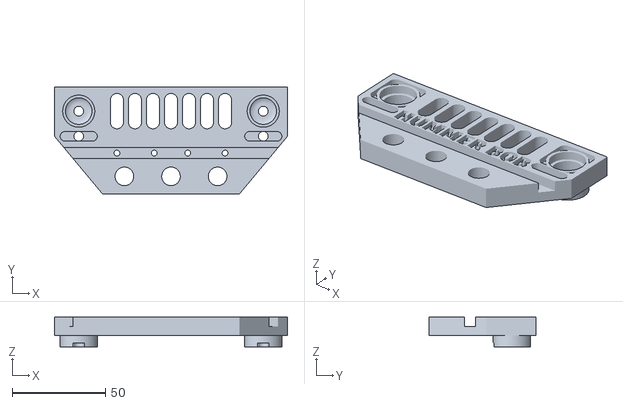
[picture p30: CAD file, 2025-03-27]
carrosserie/parts/body_front_face_v2/body_front_face_v2.stl
125.0 x 57.5 x 16.0

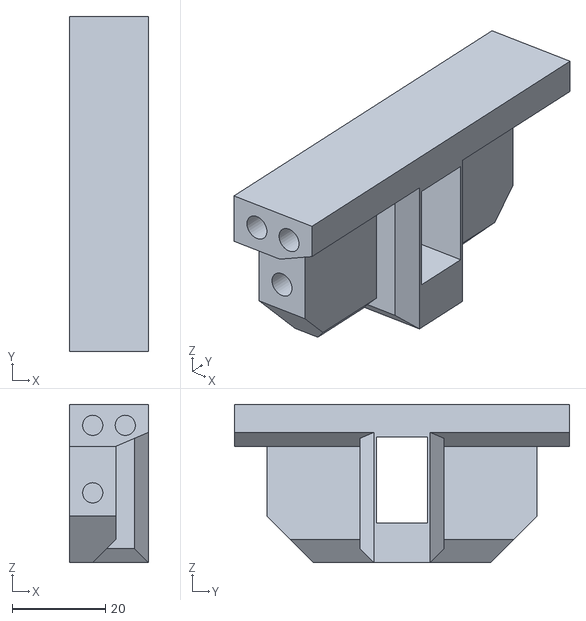
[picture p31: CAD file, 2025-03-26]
carrosserie/parts/hinge_hood_front_v3/hinge_hood_front_v3.stl
17.0 x 72.0 x 34.0

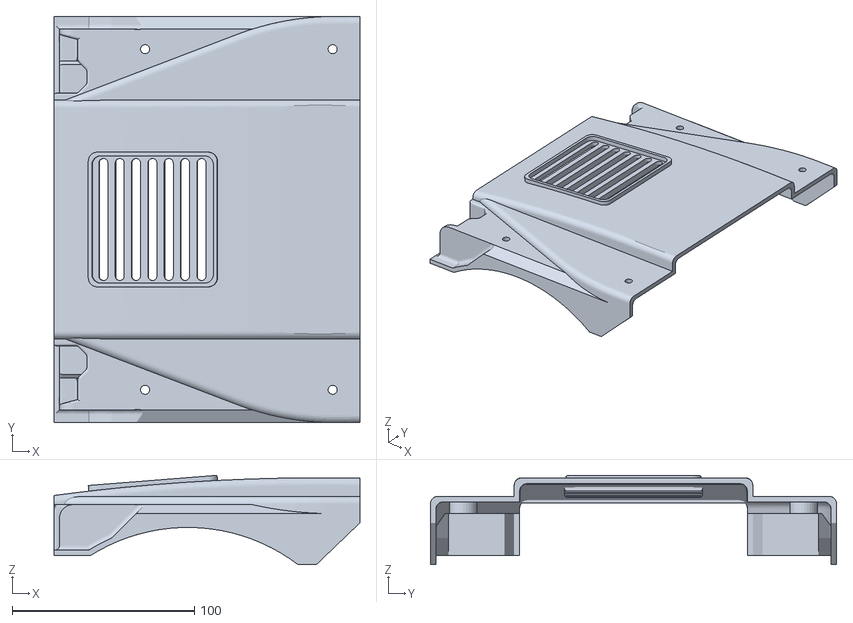
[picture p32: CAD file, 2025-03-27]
carrosserie/parts/hood/hood.stl
168.0 x 223.0 x 49.1

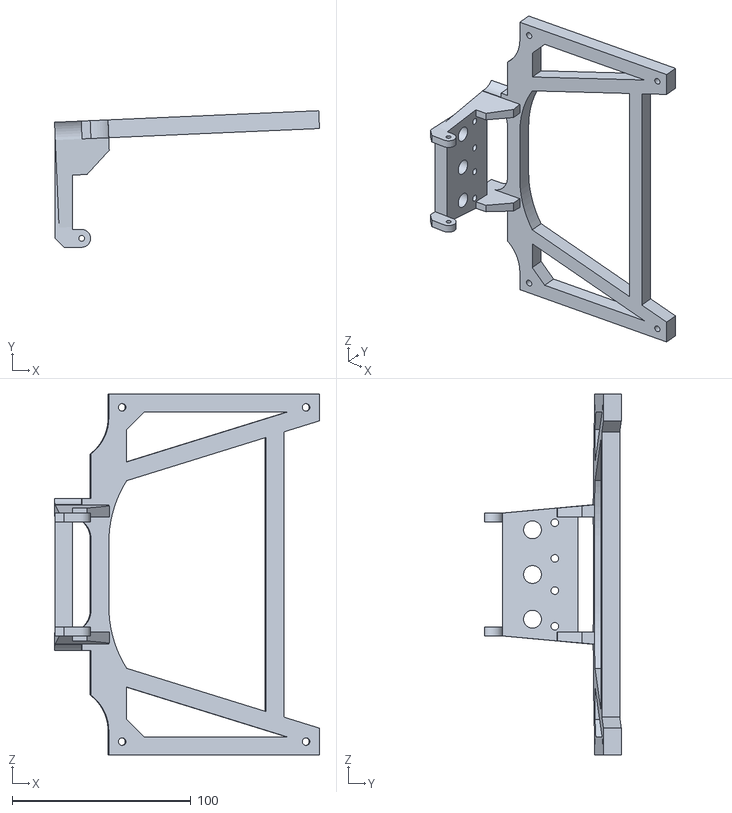
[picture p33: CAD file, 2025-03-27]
carrosserie/parts/hood_mount_frame_v3/hood_mount_frame_v3.stl
148.3 x 76.5 x 202.0

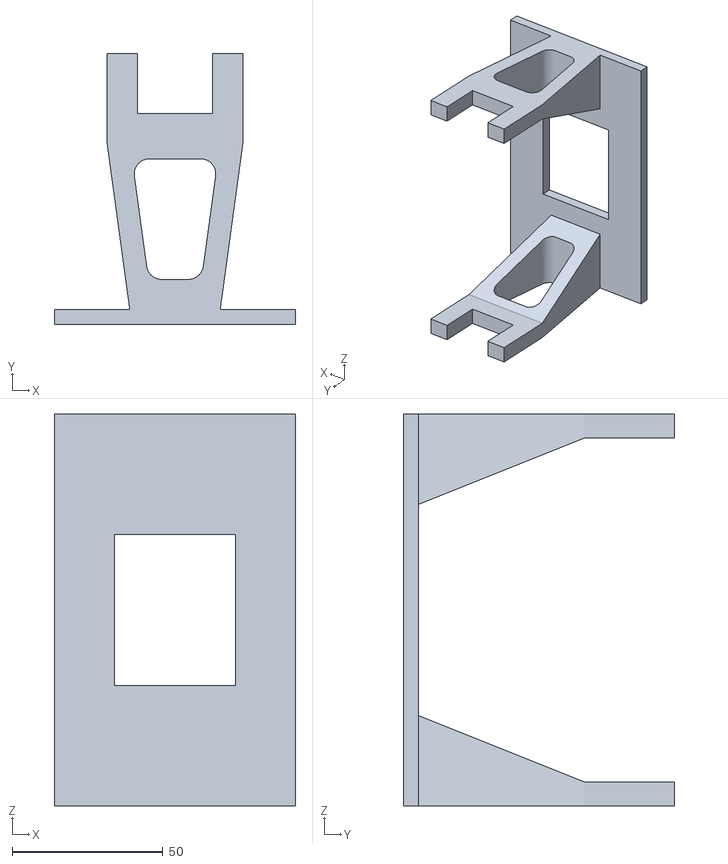
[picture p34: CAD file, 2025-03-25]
carrosserie/parts/jack_stands/jack_stands_R.stl
80.0 x 90.0 x 130.0

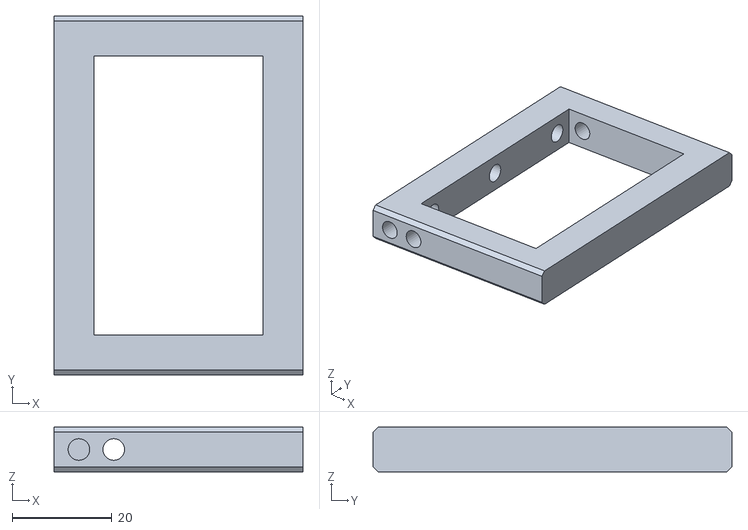
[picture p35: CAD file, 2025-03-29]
carrosserie/parts/rear_chassis_brace/rear_chassis_brace.stl
50.0 x 72.0 x 9.00

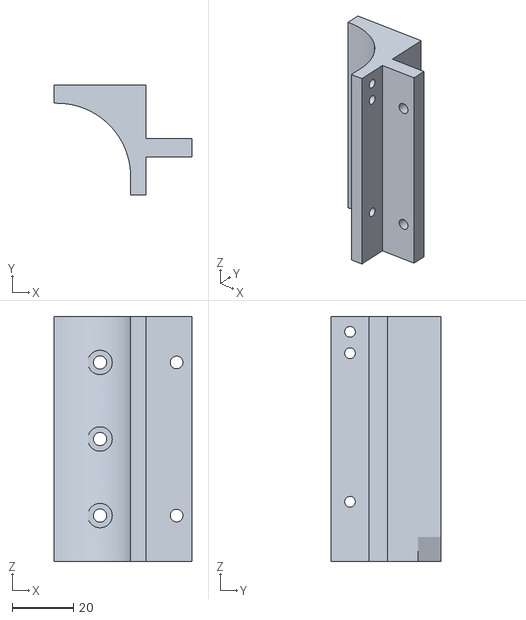
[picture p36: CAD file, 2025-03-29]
carrosserie/parts/rear_mount_v2/rear_mount_right_v2.stl
45.0 x 36.0 x 80.0

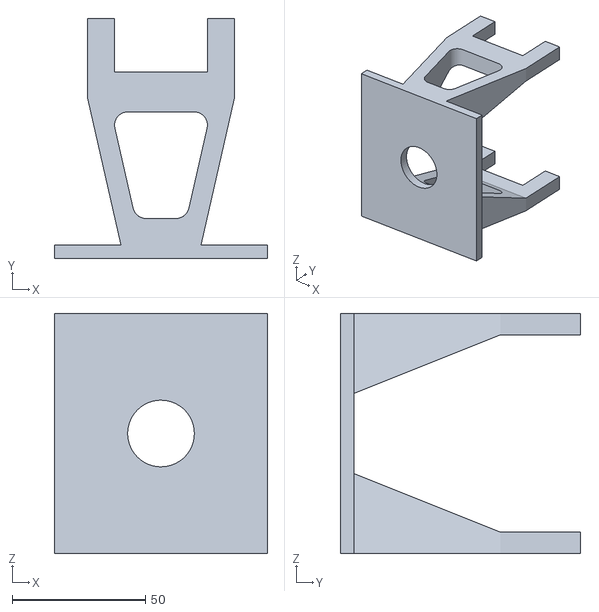
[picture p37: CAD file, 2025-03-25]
carrosserie/parts/jack_stands/jack_stands_F.stl
80.0 x 90.0 x 90.0

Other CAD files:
carrosserie/parts/angel/angel v1.f3d
carrosserie/parts/body_front_face_v2/body_front_face_v2.f3d
carrosserie/parts/hinge_hood_front_v3/hinge_hood_front_v3.f3d
carrosserie/parts/hood/hood.f3d
carrosserie/parts/hood_mount_frame_v3/hood_mount_frame_v3.f3z
carrosserie/parts/jack_stands/jack_stands_R.f3d
carrosserie/parts/jack_stands/jacks_Stands_F.f3d
carrosserie/parts/rear_chassis_brace/rear_chassis_brace.f3d
carrosserie/parts/rear_mount_v2/rear_mount_right_v2.f3d
